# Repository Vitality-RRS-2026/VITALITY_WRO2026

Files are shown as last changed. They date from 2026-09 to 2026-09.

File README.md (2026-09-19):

<p align="center">
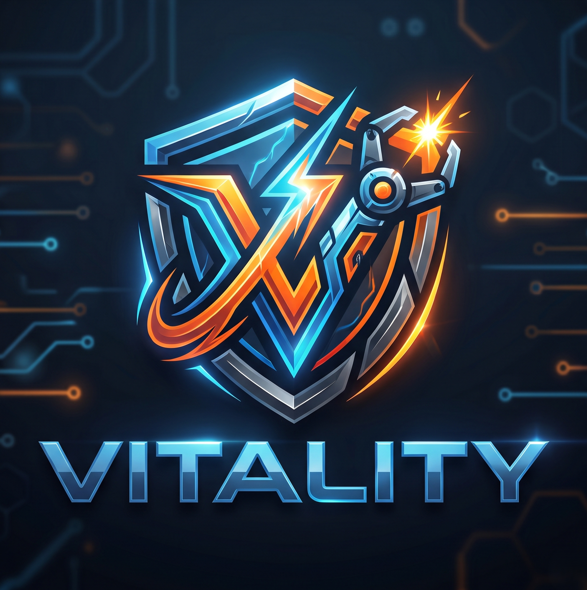
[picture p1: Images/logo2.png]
Team Vitality logo
  
</p>

<h1 align="center">⚡ WRO 2026 Future Engineers — Team Vitality</h1>

<p align="center">
  <a href="https://www.instagram.com/vitality2026.wro?stkn=dWI4NWJjdDJrMzQw">
    
  </a>
  <a href="https://youtu.be/qGNv-WUXziQ">
    
  </a>
</p>

---

## 👥 The Team

We are **Team Vitality**, three final-year high school students from Nairobi,
Kenya, competing in the **World Robot Olympiad™ (WRO®) Future Engineers 2026**
category.

| Member | Age | Year |
|---|---|---|
| **Ronak Agarwal** | 17 | Final year of high school |
| **Saurabh Rawat** | 17 | Final year of high school |
| **Raghav Mathur** | 17 | Final year of high school |

<!-- TEAM PHOTO — replace when uploaded -->
<p align="center">
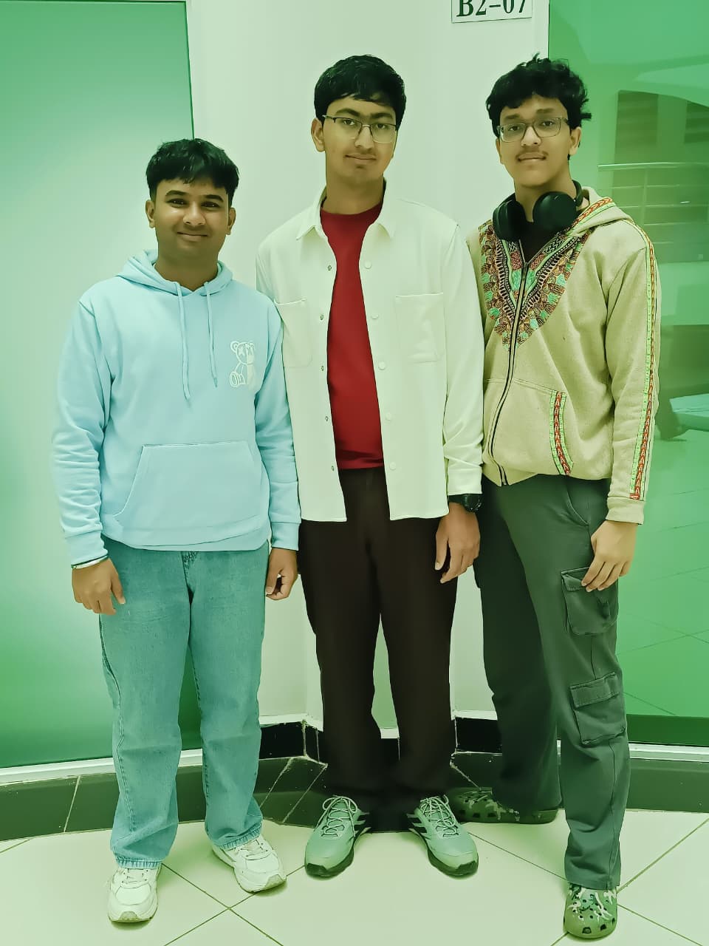
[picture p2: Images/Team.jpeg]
Team Photo
  
</p>

This is our first year in the Future Engineers category. We designed our own
Ackermann steering axle rather than buying an RC chassis, built the vehicle
around an **ESP32** and an **OpenMV Cam H7+**, and debugged our way through a
series of genuinely difficult electrical and mechanical failures — all of which
are documented honestly below, because that is where most of the engineering
actually happened.

*Last updated: [DATE]*

---

## 📸 The Vehicle

<table>
  <tr>
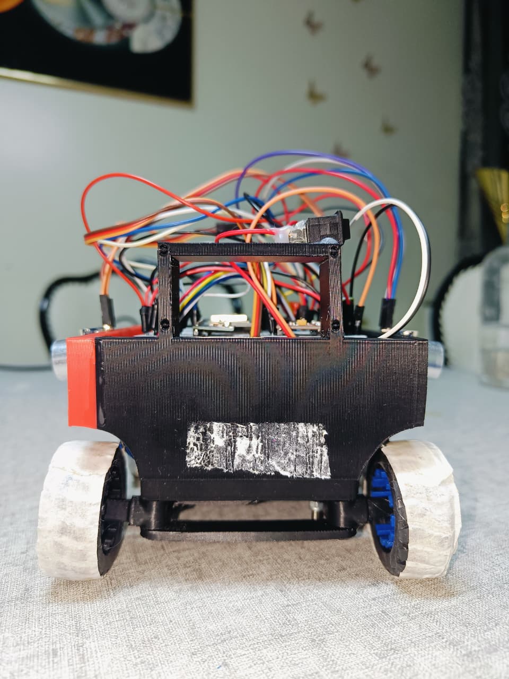
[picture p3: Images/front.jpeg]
    <td align="center"><br><b>Front</b></td>
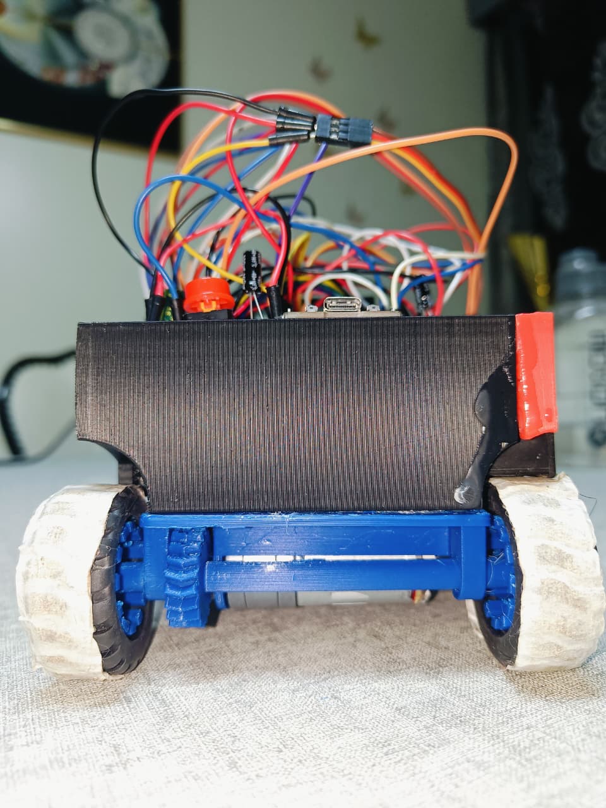
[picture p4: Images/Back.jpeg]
    <td align="center"><br><b>Back</b></td>
  </tr>
  <tr>
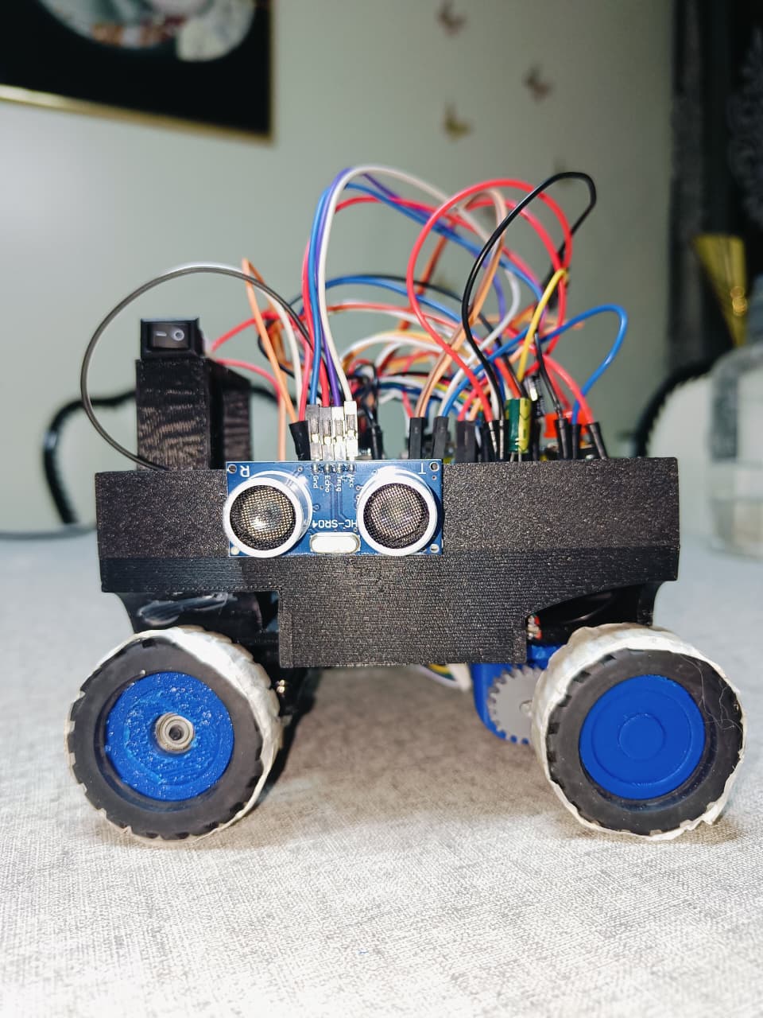
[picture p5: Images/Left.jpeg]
    <td align="center"><br><b>Left</b></td>
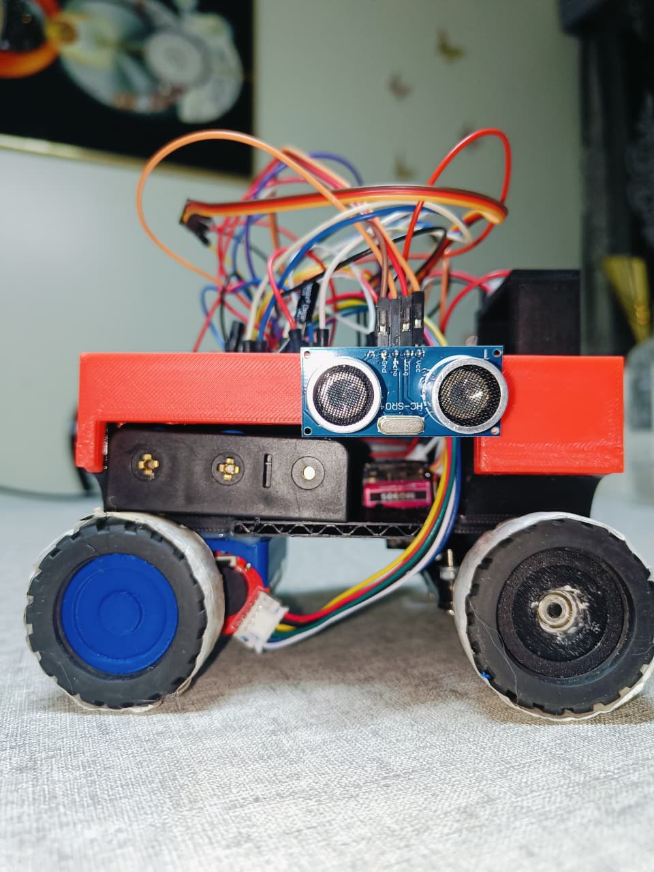
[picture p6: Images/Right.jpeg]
    <td align="center"><br><b>Right</b></td>
  </tr>
  <tr>
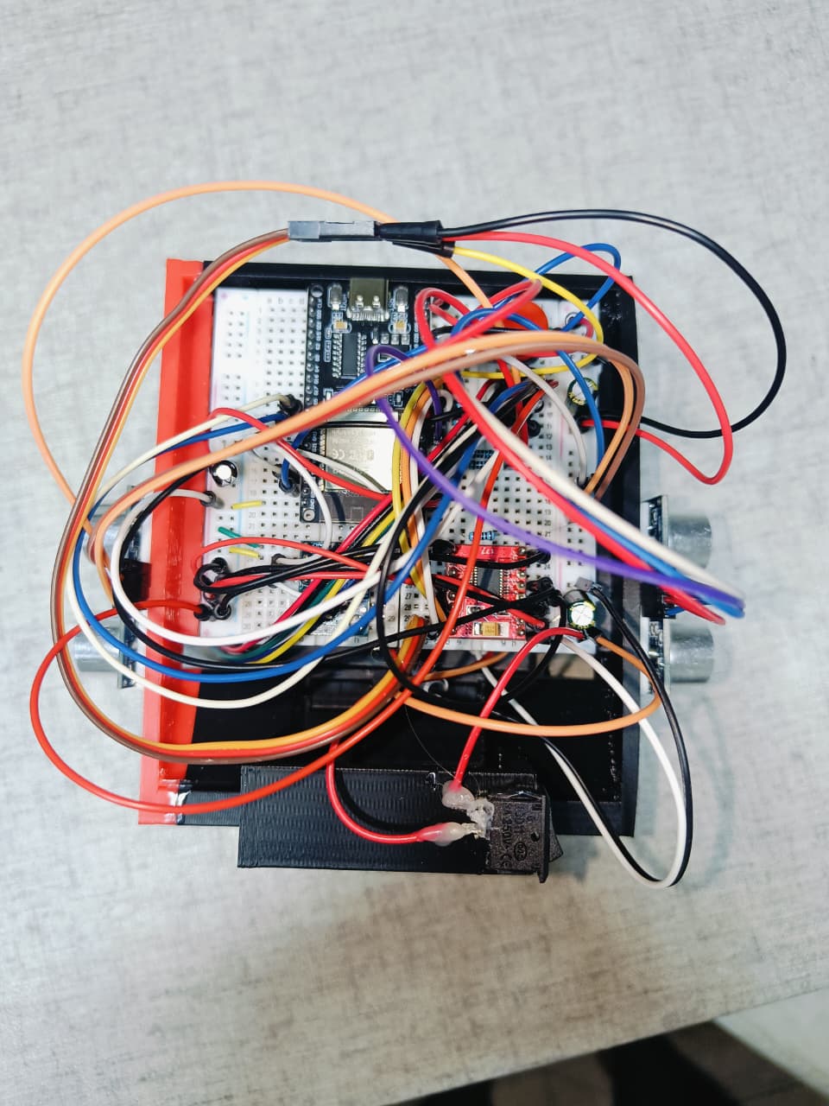
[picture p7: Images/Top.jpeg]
    <td align="center"><br><b>Top</b></td>
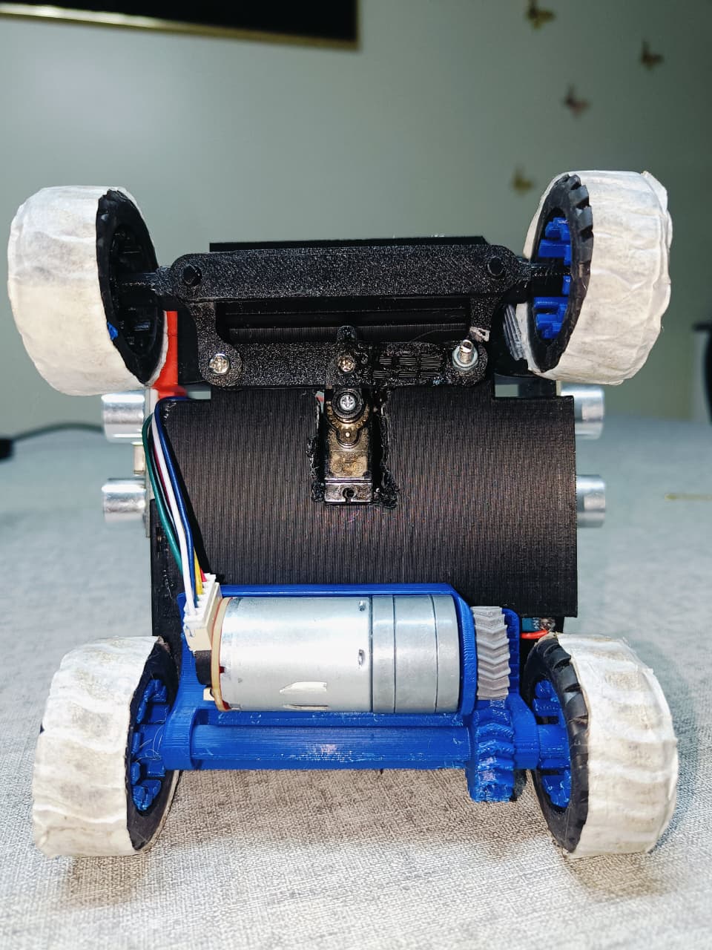
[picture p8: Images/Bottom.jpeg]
    <td align="center"><br><b>Bottom</b></td>
  </tr>
</table>

**Front** — the forward ultrasonic sensor mount and the Ackermann front axle.
**Back** — the rear drive axle, motor and gear train.
**Left / Right** — the two side ultrasonic sensors that drive wall following,
mounted level with the chassis so their readings stay square to the walls.
**Top** — ESP32 on a breadboard with the full wiring loom.
**Bottom** — the underside showing the steering linkage, servo, and the blue
rear axle assembly with the motor driving through a gear pair.

---

## 🔧 Where It Was Built

<p align="center">
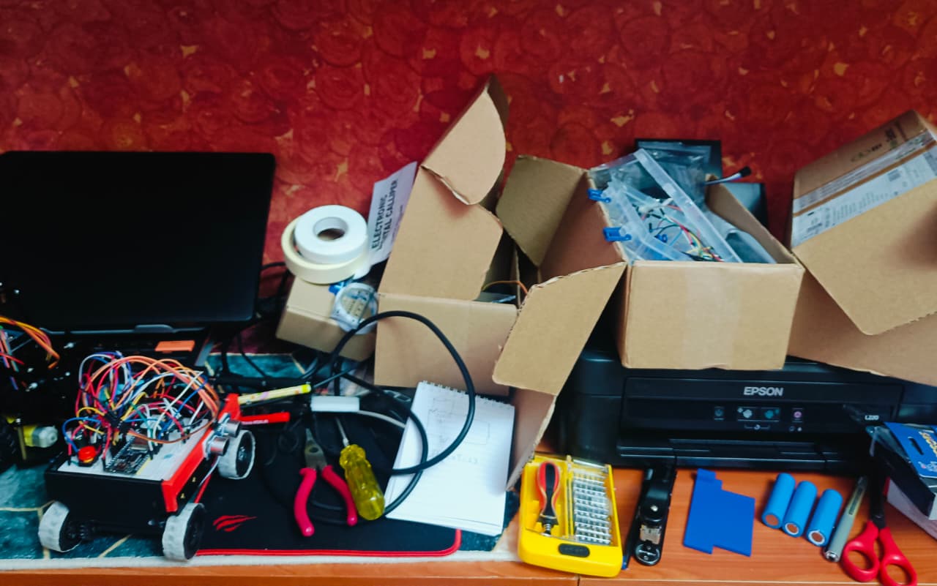
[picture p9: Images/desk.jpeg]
  <br>
  <em>The workbench through the build — prototyping, debugging and a great
  many spare parts.</em>
</p>

---

## 📑 Table of Contents

- [📸 The Vehicle](#-the-vehicle)
- [🎯 Challenge Overview](#-challenge-overview)
- [🤖 Our Vehicle](#-our-vehicle)
- [⚙️ Mobility and Mechanical Design](#️-mobility-and-mechanical-design)
- [🔋 Power and Sensor Architecture](#-power-and-sensor-architecture)
- [🧩 Components](#-components)
- [🖨️ 3D Printed Models](#️-3d-printed-models)
- [💻 Software Architecture](#-software-architecture)
- [⚖️ Engineering Decisions and Trade-offs](#️-engineering-decisions-and-trade-offs)
- [🔥 Failure Log](#-failure-log)
- [🛠️ Build and Upload Instructions](#️-build-and-upload-instructions)
- [🚧 Known Limitations and Future Work](#-known-limitations-and-future-work)
- [📜 License](#-license)

---

## 🎯 Challenge Overview

The competition runs on a 3000 × 3000 mm track with two challenges.

### 🏁 Open Challenge

Three autonomous laps. Inner wall positions are randomised per round, so each of
the four sections is either **1000 mm or 600 mm wide**, decided by coin toss
after the check time. The starting section, starting zone, and driving direction
(clockwise or counter-clockwise) are also randomised.

**What this forces on the design:** nothing about the track can be hard-coded.
The robot must discover its driving direction at runtime and tolerate a lane
that narrows by 40% without warning.

### 🚧 Obstacle Challenge

Three laps with red and green pillars (50 × 50 × 100 mm) placed randomly, then
parallel parking between two magenta markers.

Per the rules, a **red pillar means keep to the right side of the lane** and a
**green pillar means keep to the left**. Passing a pillar on the wrong side ends
the round as soon as the vehicle fully crosses the line where that pillar sits —
an incorrect pass is not a small penalty, it terminates the run.

---

## 🤖 Our Vehicle

| Property | Value | Limit |
|---|---|---|
| Dimensions (L × W × H) | **140 × 140 × 150 mm** | 300 × 200 × 300 mm ✅ |
| Mass | **550–600 g** | 1500 g ✅ |
| Drive | Rear-wheel drive, single GA25-370 geared motor with encoder | — |
| Steering | Front Ackermann axle, MG90S servo | — |
| Controller | ESP32 (ESP32-WROOM-32) | — |
| Vision | OpenMV Cam H7+ over UART | — |
| Battery | 3S Li-ion (11.1 V nominal, 12.6 V full) | — |

<p align="center">
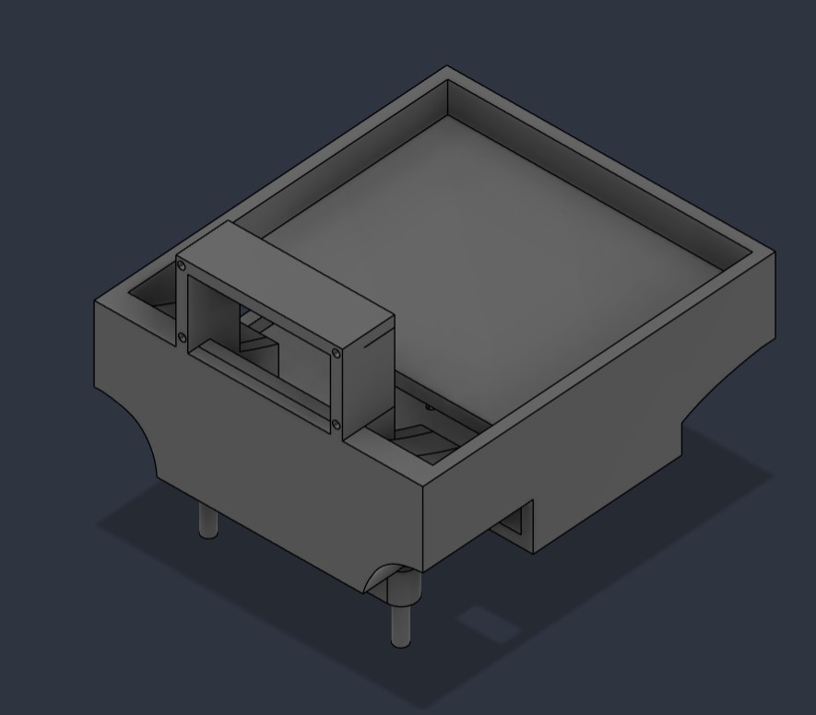
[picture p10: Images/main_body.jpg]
Main chassis CAD
  <br>
  <em>Main chassis — electronics bay, camera mast, and integrated front axle mount</em>
</p>

---

## ⚙️ Mobility and Mechanical Design

### 🔩 Why Ackermann steering

The rules require a vehicle with **one driving axle and one steering actuator**,
and explicitly disqualify differential-drive robots. We designed our own front
Ackermann axle so that we could control — and justify — every dimension.

Ackermann geometry angles the two front wheels differently in a turn so both
roll along arcs about a common centre instead of scrubbing. The steering arm on
each knuckle must point from its **kingpin** at the centre of the rear axle.

<p align="center">
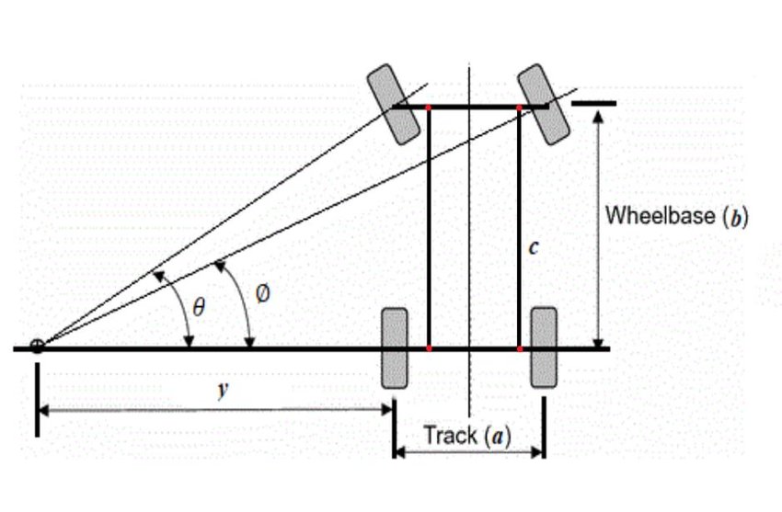
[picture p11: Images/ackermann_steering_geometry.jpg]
Ackermann geometry
  <br>
  <em>Ackermann geometry: inner wheel angle θ and outer wheel angle Ø differ so both
  wheels share one turn centre. Track (a), wheelbase (b).</em>
</p>

```
arm angle = atan(kingpin_offset / wheelbase)
```

**This is where we made our first significant error.** Our initial design used
half the track width instead of the kingpin offset, giving 24.2°. The correct
figure for our geometry is:

```
atan(27 mm / 100 mm) = 15.1°
```

The wrong value produces excessive toe-out in corners — the inner wheel steers
far more than the geometry wants and both tyres scrub. We caught it while
re-deriving the linkage from first principles and corrected it.

### 📐 Turning radius

```
R = wheelbase / tan(wheel angle)
```

| Wheel angle | Radius (mm) | 90° arc length (mm) |
|---|---|---|
| 10° | 567 | 891 |
| 15° | 373 | 586 |
| 20° | 275 | 432 |
| 25° | 214 | 337 |

Our linkage (10 mm horn arm driving a 20 mm knuckle arm, ratio 0.5) initially
gave only about 11° at the wheels from ±25° of servo travel — a **500 mm
radius**, too wide for the corners. We increased steering travel after measuring
this.

Rather than trusting the formula, the robot **measures its own turning radius**
using `R = arc_length / angle_in_radians`, taking arc length from the encoder and
angle from the gyro. This captures tyre slip and linkage slop that the formula
ignores.

### 🔧 The steering mechanism

<p align="center">
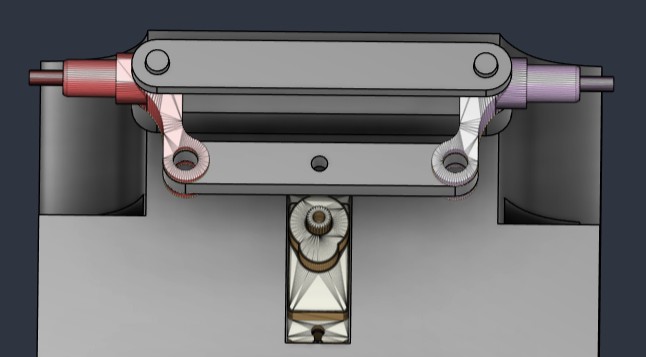
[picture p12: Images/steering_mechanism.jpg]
Steering mechanism assembly
  <br>
  <em>Complete front axle: servo (bottom centre) drives the horn, which pushes two
  tie rods out to the left and right steering arms. Both knuckles pivot on kingpins.</em>
</p>

<p align="center">
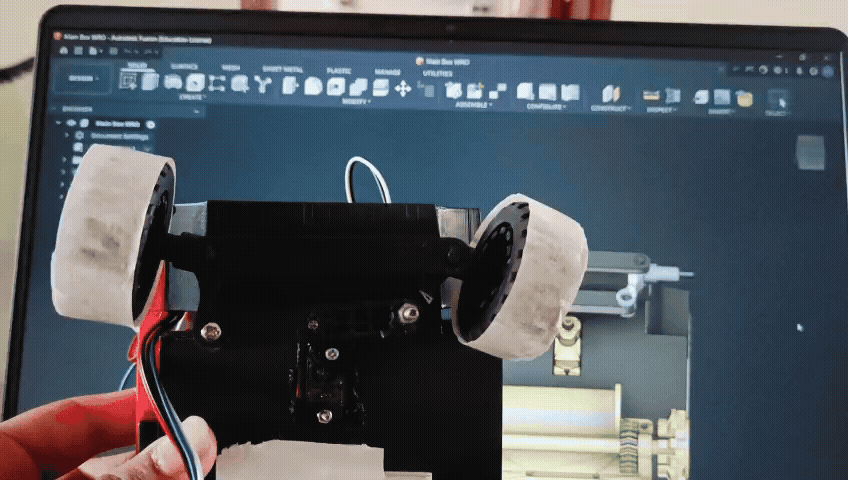
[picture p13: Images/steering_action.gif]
Steering in motion
  <br>
  <em>The assembled mechanism steering through its full travel</em>
</p>

### 🏗️ Structural iteration

The first knuckle design hung from a single M3 bolt threaded into the base plate
— a cantilever in single shear, with the wheel load acting 18 mm outboard of the
kingpin. We identified this as a failure point **before** it broke and redesigned
it as a **yoke**: the kingpin now passes through the plate, the knuckle, and a
lower arm beneath, capturing it at both ends in **double shear**.

The support towers are **lofted rather than straight** — narrow at the pivot,
flaring where they meet the plate. This gives a root cross-section of about
225 mm² against 72 mm² for a plain column: a **3.1× increase** exactly where the
bending moment is highest. A cross-beam ties the two towers together, making
plate, towers and beam a single rigid axle carrier.

### 🛞 The scrub problem (unresolved)

<p align="center">
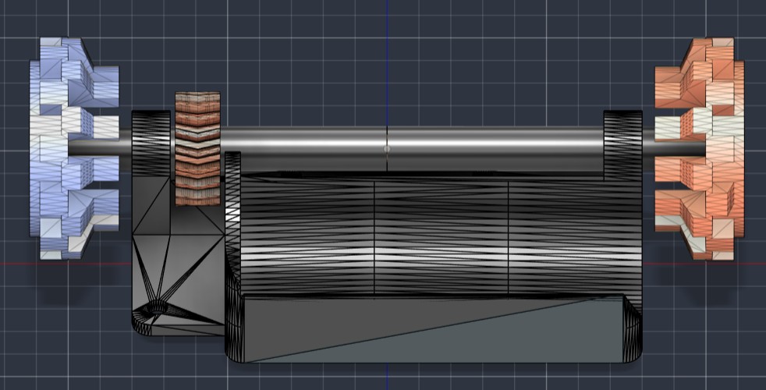
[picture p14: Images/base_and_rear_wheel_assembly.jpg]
Rear axle assembly
  <br>
  <em>Rear axle: both wheels fixed to a single solid shaft driven by the motor</em>
</p>

Our rear axle is a solid shaft — both wheels turn at the same speed. In a corner
the outer wheel must travel further than the inner one, and the difference is
fixed by track width alone:

```
difference = track_width × turn_angle_in_radians
           = 90 mm × (π/2) = 141 mm per 90° corner
```

Over 12 corners that is **1.7 metres of forced tyre scrub**. It does not improve
with a wider turn — only track width matters.

**Options we evaluated:**

| Option | Effect | Cost | Decision |
|---|---|---|---|
| Bevel-gear differential | Eliminates scrub | Days of CAD; printed bevel gears usually bind at this scale | ❌ Not achievable in remaining time |
| Free one rear wheel | Eliminates scrub | 15 minutes | ❌ Rejected on rules risk — drive wheels must be physically connected |
| Low-friction tape on rear tyres | Reduces grip so wheels slip | 5 minutes | ❌ Tried, no measurable improvement — tape over knobbly tread doesn't sit flat |
| Narrow the rear tyres | Smaller contact patch resists twisting less | 20 minutes | ⏳ Recommended next step |
| Reduce cornering speed | Spreads scrub over time rather than reducing it | Free | ✅ Implemented as mitigation |

This is an honest open problem in our design and the clearest target for our next
iteration.

---

## 🔋 Power and Sensor Architecture

### ⚡ The power failure that cost us the most time

Our original design used a **2S Li-ion pack (8.4 V)** with:
- a **CN6009 boost converter** raising 8.4 V → 12 V for the motor
- an **LM2596 buck converter** dropping 8.4 V → 5 V for everything else

The robot worked on a fully charged pack and failed completely once cell voltage
fell from 4.20 V to 4.15 V. A 0.05 V change causing total failure is not how a
battery problem behaves — that sharp threshold pointed at a regulator.

**Root cause: a boost converter draws more current in than it delivers out.**

```
input current = (output voltage × output current) / (input voltage × efficiency)
```

| Pack voltage | Motor at 1.0 A | Motor at 2.0 A |
|---|---|---|
| 8.4 V | 1.68 A | 3.36 A |
| 8.0 V | 1.76 A | 3.53 A |
| 7.2 V | 1.96 A | 3.92 A |

As the pack sags, the boost converter demands **more** input current for the same
output. More current through holder and wiring resistance causes more sag. It is
a positive feedback loop, which is why it failed at a cliff edge instead of
degrading gradually.

**Solution: switch to 3S and delete the boost converter.** The motor now runs
directly from the pack.

| | 2S + boost | 3S direct |
|---|---|---|
| Battery current for 1 A motor | 1.68 A | 1.00 A |
| Converters in the motor path | 1 | 0 |
| Failure points | 3 | 2 |

This cut battery current by **43%** for the same motor power and removed the
feedback loop entirely.

### 🔍 Chasing 1.4 volts

Even on 3S the ESP32 reset whenever the servo moved. We measured the whole path
rather than guessing:

| Measurement point | Voltage |
|---|---|
| LM2596 output, no load | 5.11 V |
| 5 V rail, loaded | 4.90 V |
| **ESP32 VIN pin** | **3.80 V** |

The ESP32's onboard AMS1117 regulator needs roughly 1.2 V of headroom above
3.3 V. At 3.8 V it had 0.5 V and browned out. The loss was **resistance in the
wiring**, not a converter fault.

**Fixes applied:**
1. Replaced jumper wires and DuPont connectors on all power paths with **20 AWG
   silicone wire, soldered**. DuPont crimps are rated well below the 1–3 A a
   motor draws and loosen under vibration.
2. Raised converter output to compensate for the remaining drop.
3. Added **electrolytic capacitors at the loads, not at the converter** — wire
   between reservoir and load blunts the effect.

Result: rail sag under servo load fell from **0.44 V to 0.11 V**.

### 🎚️ Servo selection — measured, not guessed

We calculated the steering torque actually required rather than buying the
biggest servo available. Stationary steering torque is dominated by **scrub
torque**, because the kingpin is offset from the wheel centreplane:

```
scrub radius   = 45 mm − 27 mm = 18 mm
load per wheel = 1.5 kg × 0.45 × 9.81 / 2 = 3.31 N
scrub torque   = μ × N × r = 1.1 × 3.31 × 0.018 = 6.56 N·cm per wheel
```

Adding bore torque and both wheels gives **1.51 kg·cm at the kingpins**. The
linkage ratio (0.5) means the servo sees half: **0.76 kg·cm**.

| Servo | Torque at 6 V | Mass | Margin |
|---|---|---|---|
| **MG90S** | 2.2 kg·cm | 13.4 g | **2.9×** |
| MG996R | 11.0 kg·cm | 55.0 g | 14.6× |

**We chose the MG90S.** The MG996R offers a 14.6× margin we have no use for,
while costing 42 g and occupying 37% of the chassis width. It is also an analog
servo with significant gear backlash, and our 0.5 linkage ratio *amplifies*
backlash into wheel wander — precision matters more than torque here.

### 📡 Sensor placement

| Sensor | Purpose | Placement rationale |
|---|---|---|
| 2 × HC-SR04 ultrasonic | Wall following, corner detection | Left and right, facing outward. Lane is 600–1000 mm wide, well within range |
| MPU6050 IMU | Heading during turns | Gyro Z axis only; accelerometer unused |
| Motor encoder | Distance, turning-radius measurement | On the drive motor |
| OpenMV Cam H7+ | Pillar colour and position | Forward-facing on a mast, tilted down |

The ultrasonics fire **one per control loop, alternating**. Firing both together
causes crosstalk — each hears the other's echo. Their ECHO pins connect through
**1 kΩ / 2 kΩ dividers** to drop the 5 V signal to 3.33 V, and use GPIO 34 and
35, which are input-only.

### 🔌 Pin map

| GPIO | Function |
|---|---|
| 14 | Servo signal |
| 16 / 17 | UART2 RX / TX ↔ OpenMV camera |
| 18 / 19 | Encoder A / B |
| 21 / 22 | I²C SDA / SCL (MPU6050) |
| 23 | Start button → GND |
| 25 / 26 / 27 | Motor PWMA / AIN1 / AIN2 |
| 32 / 33 | Ultrasonic TRIG left / right |
| 34 / 35 | Ultrasonic ECHO left / right (input-only) |

---

## 🧩 Components

| Component | Image | Qty | Function | Key specifications |
|---|---|---|---|---|
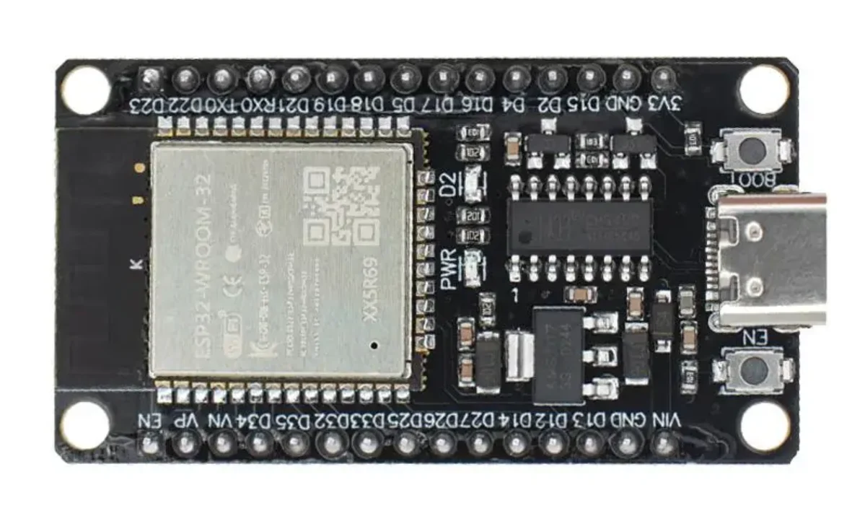
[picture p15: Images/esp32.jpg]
| **ESP32-WROOM-32** |  | 1 | Main controller | Dual-core 240 MHz, 3.3 V logic, runs all control and sensing |
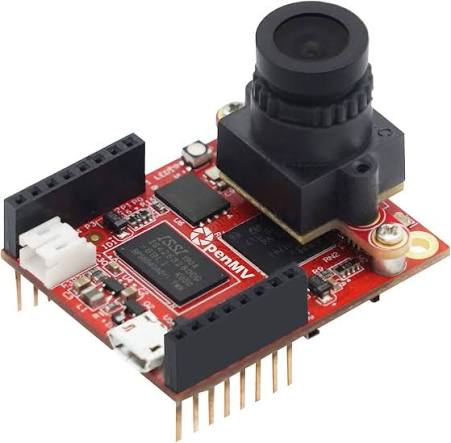
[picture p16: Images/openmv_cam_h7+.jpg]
| **OpenMV Cam H7+** |  | 1 | Vision processing | STM32H7, QVGA capture, on-board LAB blob detection |
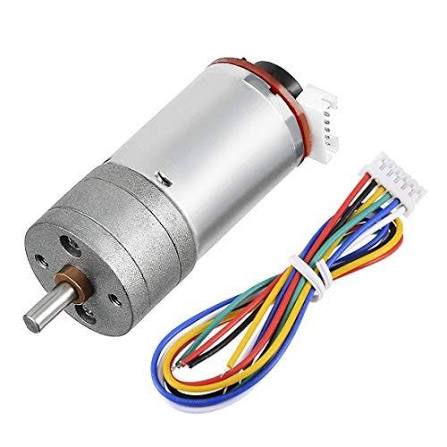
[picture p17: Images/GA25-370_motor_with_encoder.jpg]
| **GA25-370 geared motor** |  | 1 | Rear-wheel drive | 12 V DC, integrated quadrature encoder (6 wires) |
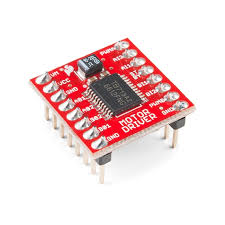
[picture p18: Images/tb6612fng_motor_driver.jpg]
| **TB6612FNG driver** |  | 1 | Motor control | Dual H-bridge, VM to 13.5 V, 3.3 V logic |
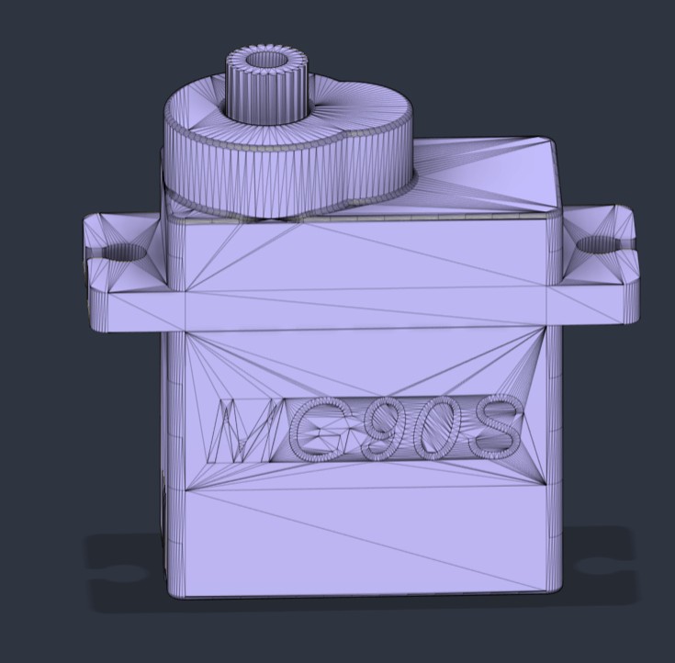
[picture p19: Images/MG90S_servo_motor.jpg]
| **MG90S servo** |  | 1 | Steering actuation | 2.2 kg·cm at 6 V, metal gears, 13.4 g |
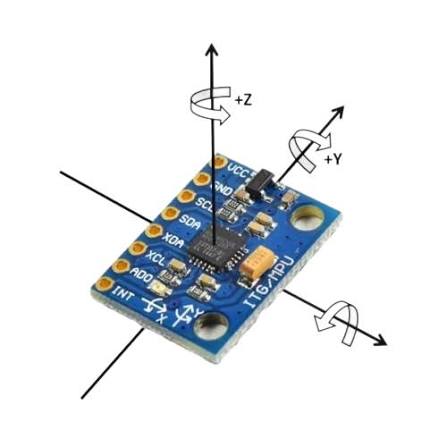
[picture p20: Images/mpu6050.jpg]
| **MPU6050 IMU** |  | 1 | Heading measurement | 6-axis, I²C, gyro Z used for yaw integration |
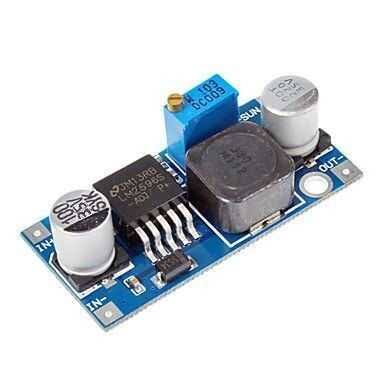
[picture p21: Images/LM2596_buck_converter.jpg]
| **LM2596 buck converter** |  | 1 | 12.6 V → 5 V | 4–35 V in, adjustable out, ~92% efficiency |
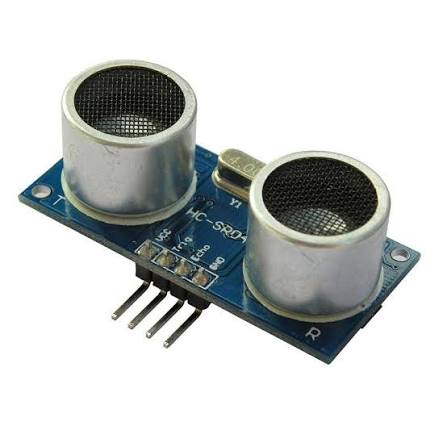
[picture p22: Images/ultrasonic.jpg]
| **HC-SR04 ultrasonic** |  | 2 | Wall distance | 5 V, 2–400 cm, ECHO through 1k/2k divider |
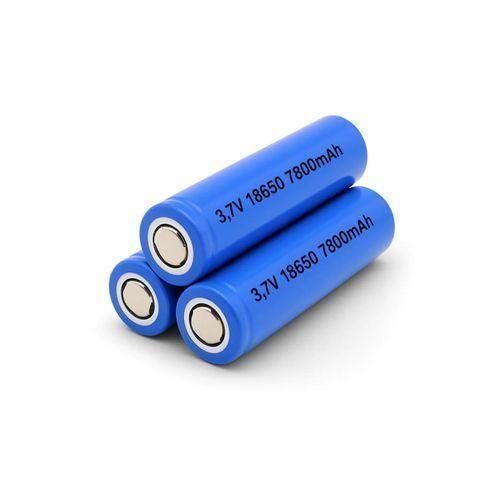
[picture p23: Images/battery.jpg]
| **3S Li-ion pack** |  | 1 | Power source | 11.1 V nominal, 12.6 V full |
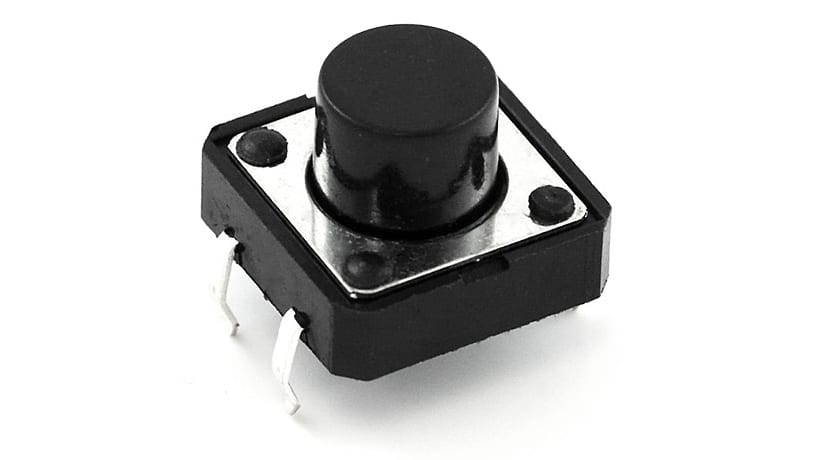
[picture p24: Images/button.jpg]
| **Push button** |  | 1 | Start trigger | GPIO 23 to GND, `INPUT_PULLUP` |

**Component selection philosophy:** we deliberately chose widely available,
well-documented parts so another team can source and reproduce this build. Every
component above is stocked by general electronics suppliers.

---

## 🖨️ 3D Printed Models

All structural parts were designed in **Fusion 360** and printed in PLA.

| Part | Image | Qty | Function |
|---|---|---|---|
| **Main body** |  | 1 | Primary chassis — electronics bay, camera mast mount, front axle interface |
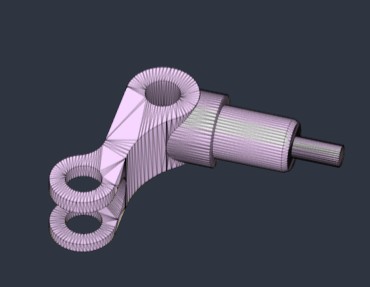
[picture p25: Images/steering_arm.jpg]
| **Steering arm (knuckle)** |  | 2 | Carries the stub axle and pivots on the kingpin; the angled arm sets Ackermann geometry |
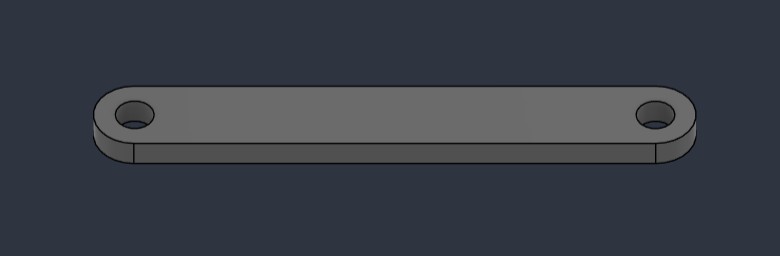
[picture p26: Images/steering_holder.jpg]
| **Steering holder** |  | 1 | Servo mount and kingpin support structure |
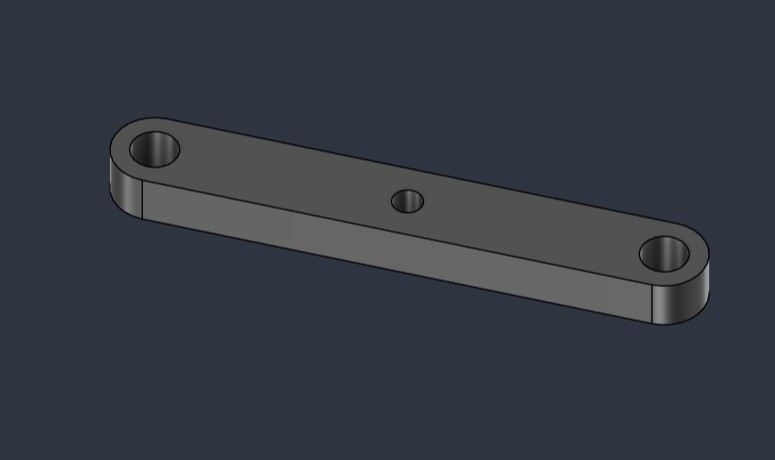
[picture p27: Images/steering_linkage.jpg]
| **Steering linkage (tie rod)** |  | 2 | Connects the servo horn to each steering arm |
| **Servo horn / bell crank** |  | 1 | Converts servo rotation into linear tie-rod motion |
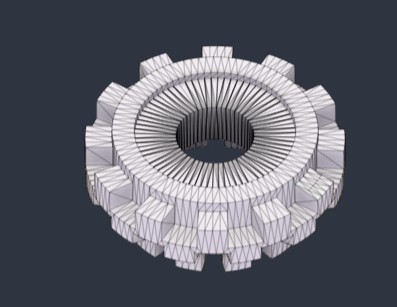
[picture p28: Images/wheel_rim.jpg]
| **Wheel rim** |  | 4 | Printed rim; rubber tyre fitted over the tread pattern |
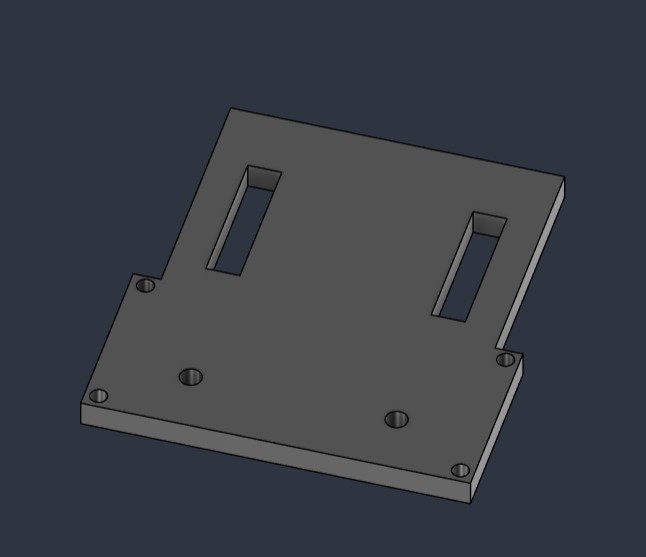
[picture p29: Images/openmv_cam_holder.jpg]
| **OpenMV camera holder** |  | 1 | Mounts the camera at a fixed downward tilt so the view stays repeatable |

<p align="center">
  Steering arm detail
  Steering linkage detail<br>
  <em>Left: steering arm with integrated stub axle and angled Ackermann arm.
  Right: tie rod linking horn to knuckle.</em>
</p>

**Print notes:** parts print without supports in the orientations supplied.
The steering components use higher perimeter counts, since the tie rods and
steering arms carry the full cornering load through relatively thin sections.

---

## 💻 Software Architecture

### 🔀 Processing split

```
OpenMV Cam H7+                    ESP32
──────────────                    ─────
Image capture                     Ultrasonic ranging
LAB colour thresholding    UART   Gyro integration
Blob detection            ─────▶  State machine
Dominant colour choice    115200  PD wall following
                                  Servo + motor output
```

Vision runs entirely on the OpenMV so the ESP32 never blocks on image processing.
The link is one-way at 20 Hz; the ESP32 control loop runs at 50 Hz.

### 🔄 Open Challenge state machine

```
   ┌──────┐  button   ┌───────┐  wall lost   ┌─────────┐
   │ WAIT │ ────────▶ │ DRIVE │ ───────────▶ │ TURNING │
   └──────┘           └───────┘              └─────────┘
                          ▲                       │
                          └───────────────────────┘
                            90° swept, heading snapped

   after 12 corners:  DRIVE ──▶ FINISHING ──▶ DONE
```

### 🧭 Wall following

<p align="center">
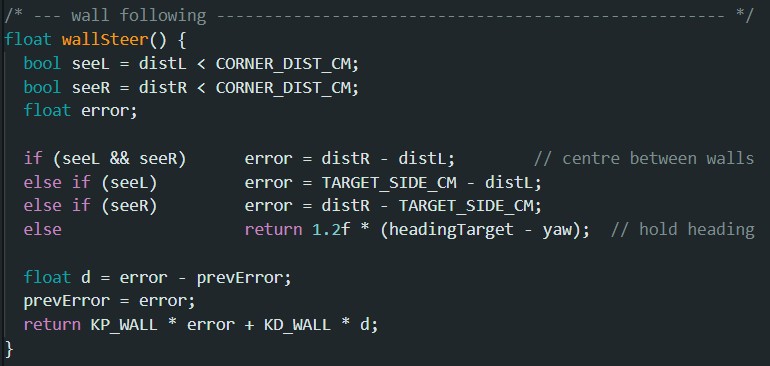
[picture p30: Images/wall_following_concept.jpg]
Wall following code
  <br>
  <em>PD wall-following controller with graceful degradation as walls disappear</em>
</p>

The controller handles four cases in priority order:

1. **Both walls visible** — centre between them: `error = distR − distL`
2. **Only left wall** — hold a fixed offset from it
3. **Only right wall** — hold a fixed offset from it
4. **Neither wall** — fall back to holding the gyro heading

This graceful degradation matters because the lane width changes between
sections, and at a corner one wall genuinely disappears.

### 🔁 Corner turns and drift control

<p align="center">
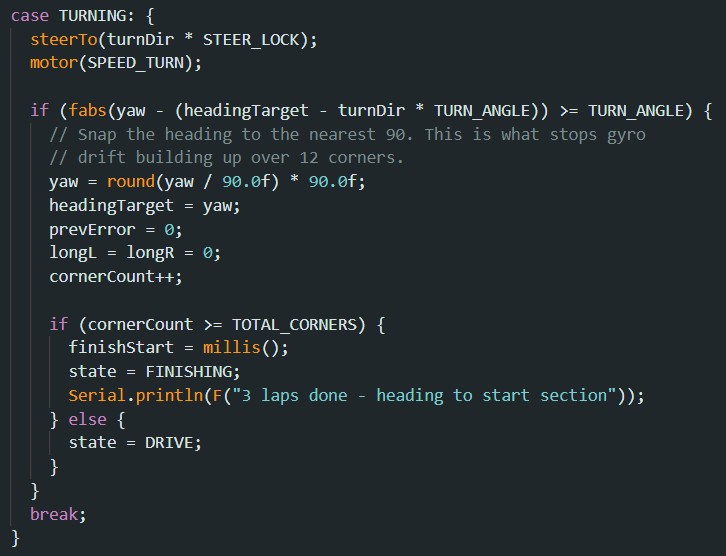
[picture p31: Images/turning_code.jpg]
Turning state machine code
  <br>
  <em>The TURNING state: gyro-measured 90° turn followed by heading snapping</em>
</p>

**Turns use the gyro, not a timer.** A timed turn varies with battery voltage and
floor grip, so it drifts over 12 corners. "Turn until the gyro says 90°" is
repeatable.

The MPU6050 reports angular *rate*, so heading comes from integration:

```
yaw += (rate − bias) × dt
```

Three measures keep drift bounded:

1. **Bias calibration** — 1500 samples averaged at startup with the robot still
2. **Deadband** — rates below 0.6 °/s treated as zero, so noise on straights
   doesn't accumulate
3. **Heading snapping** — after each corner, yaw resets to the nearest multiple
   of 90°, so each corner corrects the previous straight's error instead of
   compounding it

The third is the single most effective measure, and it is visible in the code
screenshot above.

### 🧠 Direction detection

Driving direction is randomised per round. The robot **decides at the first
corner** — whichever wall disappears first sets the turn direction, which is then
fixed for the entire run. Driving the wrong way ends the round, so this value is
never revised mid-run.

### 🎨 Vision pipeline

<p align="center">
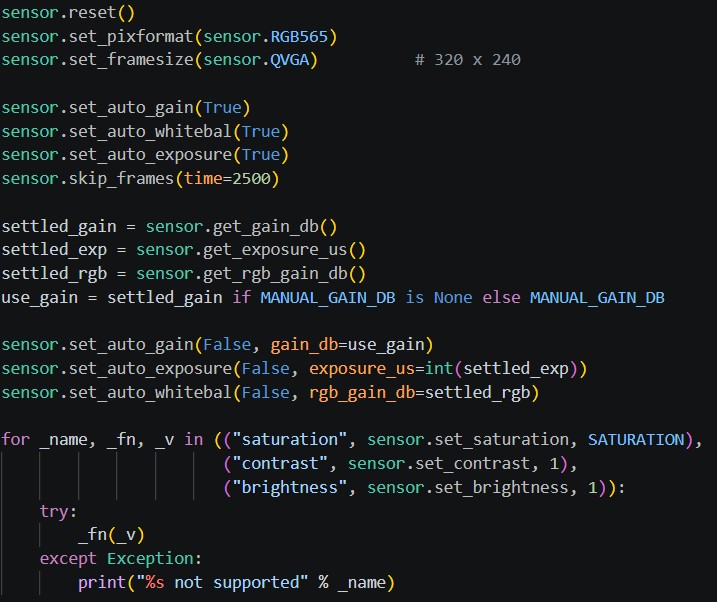
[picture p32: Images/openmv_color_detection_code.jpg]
Camera initialisation code
  <br>
  <em>Camera setup: auto-exposure settles, then gain, exposure and white balance
  are read back and locked so thresholds stay valid</em>
</p>

The locking step matters more than it looks. If auto-gain and auto-white-balance
stay enabled, the sensor continuously re-balances and the LAB thresholds drift
out from under the detection code. We let auto settle, read the settled values,
then fix all three.

**Pipeline:**
1. Capture 320 × 240 RGB565
2. Lock gain, exposure, white balance; raise saturation
3. Convert to LAB and threshold
4. Blob detection with merging, restricted to a region of interest cropping off
   the far wall
5. Choose dominant colour by **total pixel area**, take position from the
   **largest single blob** of that colour

That last distinction is deliberate. Total area answers "which colour dominates";
using it for position too would average two pillars into the gap between them,
and the robot would steer at the gap.

### 🌈 Why LAB and not RGB

LAB separates lightness (L) from colour (A and B), so a dimmer pillar of the same
colour still matches. Thresholds were derived from the official pillar colours
rather than eyeballed:

| Object | RGB | L | A | B |
|---|---|---|---|---|
| Red pillar | (238, 39, 55) | 51.7 | 72.1 | 42.7 |
| Green pillar | (68, 214, 44) | 75.8 | −67.3 | 66.4 |
| Magenta marker | (255, 0, 255) | 60.3 | 98.2 | −60.8 |

**Red and magenta are both strongly positive on A.** They separate only on B,
where red is +42.7 and magenta is −60.8. Knowing this made tuning
straightforward: if magenta reads as red, raise red's B minimum.

We also checked the **orange and blue direction lines** against the pillars. The
orange line sits only 41 units from red in LAB — close enough that lighting
variation will confuse them. Blue is 109 from red and 117 from orange. If we use
the lines for lap counting, we will **count blue only**.

### ▶️ Start procedure

The rules require one switch to power the robot on and a **separate button** to
start the program, and flag auto-start as a recurring source of penalties. Our
robot powers on, calibrates the gyro, prints `READY`, and waits on a debounced
button (GPIO 23, `INPUT_PULLUP`). Yaw zeroes on the press rather than at
power-up, so the heading reference is where the robot actually sits at the start.

---

## ⚖️ Engineering Decisions and Trade-offs

| Decision | Alternative | Why we chose it | What it costs |
|---|---|---|---|
| 3S direct drive | 2S + boost converter | Removes current-multiplication feedback loop; 43% less battery current | Extra cell mass; must not over-discharge |
| MG90S servo | MG996R | 2.9× margin is enough; saves 42 g and 37% of chassis width | Less headroom if the robot gains weight |
| Gyro-timed turns | Fixed-duration turns | Repeatable regardless of battery state | Requires IMU and calibration |
| Heading snap at corners | Continuous integration | Bounds drift instead of letting it compound | Assumes every corner is exactly 90° |
| Vision on OpenMV | Vision on ESP32 | ESP32 never blocks on image processing | Extra board and a UART link to debug |
| LAB colour space | RGB or HSV | Tolerates brightness variation | Thresholds less intuitive to read |
| Dominant colour by area, position by largest blob | Either alone | Avoids steering at the gap between two pillars | Slightly more computation |
| Ultrasonics alternating | Both simultaneously | Eliminates crosstalk | Halves update rate per sensor |
| Printed Ackermann axle | Bought RC chassis | Full control of geometry; every dimension justified | Several print-and-test cycles |
| Open Challenge first | Both challenges at once | Secures the achievable points before attempting the harder round | Obstacle Challenge left incomplete |

---

## 🔥 Failure Log

Documented honestly, because the debugging is where most of the engineering
happened.

| Symptom | Actual cause | How we found it |
|---|---|---|
| Fusion script: *"No target body found to cut"* | Sketch plane exactly coincident with the face being cut | Traced to one operation, then made all cuts start 2 mm outside the material |
| Parts generated but disconnected | Support towers at Y=+11 while the plate ended at Y=+10 — a 1 mm gap. Fusion's Join silently does nothing when bodies don't touch | Checked coordinates numerically instead of visually |
| Knuckles buried 13 mm inside the wheels | Kingpin at ±38 mm with wheel inner face at ±35 mm | Compared geometry numerically — renders looked fine because separate components can interpenetrate |
| Battery collapsed 8.2 V → 0.8 V, wire overheated | Damaged cells and holder contact resistance | Measured under load rather than at rest |
| Worked at 4.20 V per cell, dead at 4.15 V | Boost converter current-multiplication feedback loop | The sharpness of the threshold pointed at a regulator, not a battery |
| ESP32 resetting whenever the servo moved | 1.4 V lost between rail and VIN pin in wiring and connectors | Measured voltage at four points along the path |
| OpenMV: *"'tuple' object isn't callable"* | Firmware 4.5+ changed blob accessors from methods to properties | Wrote a helper accepting both conventions |
| Camera image dark and desaturated | Scene under-lit; auto-exposure already at its limit | Measured frame brightness while sweeping gain and exposure |
| Servo wouldn't move in the combined sketch | ESP32Servo and motor PWM competing for LEDC timers | Worked in isolation; fixed by initialising the servo first on separate timers |
| Spark and bang; ESP32 destroyed | 12.6 V line contacted the 5 V rail | Visible component failure on the board |

**Mitigation after the short circuit:** inline fuse on the battery positive lead,
12.6 V and 5 V runs physically separated and routed on opposite sides, heatshrink
over every exposed terminal, and battery leads mechanically secured so they
cannot shift under vibration.

---

## 🛠️ Build and Upload Instructions

### Requirements

- **Arduino IDE** with ESP32 board support
- Library: **ESP32Servo** (Library Manager). The MPU6050 is driven through raw
  register access over `Wire.h`, so no IMU library is needed.
- **OpenMV IDE** for the camera

### ESP32

1. Open the sketch from `src/`
2. Select your ESP32 board and port
3. Set `TUNING_MODE` to `1` for the first upload — the motor stays disabled while
   sensors print at 10 Hz
4. Upload and open Serial Monitor at **115200**

### OpenMV

1. Open the `.py` file from `src/` in OpenMV IDE
2. Verify detection in the frame buffer
3. **Tools → Save open script to OpenMV Cam (As Main Script)** — pressing Run only
   loads it into RAM and it is lost on power-cycle

### 📋 Calibration order

These are interdependent; doing them out of order wastes time.

1. **`ENCODER_TICKS_PER_REV`** — rotate the wheel 10 turns by hand and read the
   count. Every distance measurement depends on it.
2. **Motor direction and deadband** — confirm forward gives positive ticks; find
   the lowest PWM that moves the shaft.
3. **`SERVO_CENTER`** — on blocks, adjust until the wheels are truly straight. An
   off-centre value makes the robot curve constantly and **no amount of PD tuning
   fixes it**. This is the most common cause of wall-following failure.
4. **`KP_WALL`** — raise until the robot weaves, then back off ~30%. Leave
   `KD_WALL` until KP is close.
5. **`CORNER_DIST_CM`** — read what the side sensors actually report on a
   straight, then set the threshold well above it.
6. **Colour thresholds** — OpenMV IDE → Tools → Machine Vision → Threshold Editor,
   under the lighting you will actually compete in.

---

## 🚧 Known Limitations and Future Work

We would rather state these plainly than omit them.

**Rear axle scrub.** No differential — 141 mm of forced scrub per corner. Next
step is narrowing the rear tyres; the proper fix is a differential.

**Obstacle Challenge incomplete.** Colour detection and steering response work,
but pillar avoidance is not reliable enough to compete, and parking is not
implemented. We prioritised a working Open Challenge over an unreliable Obstacle
attempt, because passing a pillar on the wrong side ends the round.

**Lighting dependence.** Until robot-mounted lighting is fitted, thresholds must
be re-tuned at the venue.

**No speed control loop.** The encoder measures distance but does not close a loop
on speed, so the robot slows as the battery drains. The PWM-to-speed curve is
markedly non-linear, which is why open-loop PWM is not equivalent to commanding a
speed.

**Timed finish.** Stopping in the start section uses a tuned drive time after the
twelfth corner rather than encoder distance — adequate, but sensitive to speed
changes.

### Planned improvements

- ⚙️ Differential, or narrowed rear tyres, to eliminate scrub
- 💡 Robot-mounted LEDs for lighting independence
- 🔁 Closed-loop speed control using the existing encoder
- 🔵 Blue-line counting as an independent cross-check on gyro corner counting
- 📏 Encoder-based finish positioning

---

## 📜 License

GNU Affero General Public License v3.0

This repository will remain public for at least 12 months after the competition.

---

<p align="center">
  Team Vitality<br>
  <strong>Team Vitality</strong><br>
  <em>WRO 2026 Future Engineers</em>
</p>

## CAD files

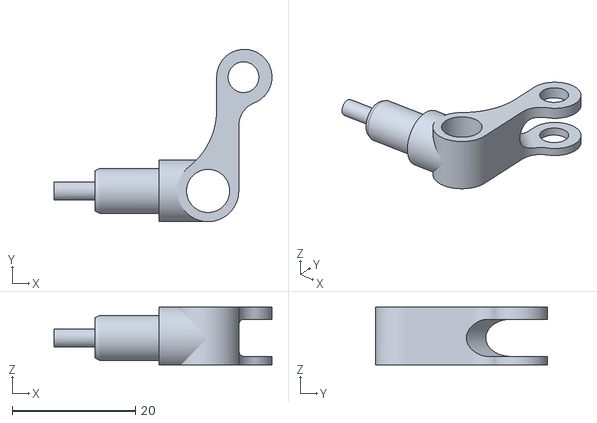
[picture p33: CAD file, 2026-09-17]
Finished Models/Main Box WRO_Configuration 1_design_steering_arm_left.stl
35.4 x 28.0 x 9.40

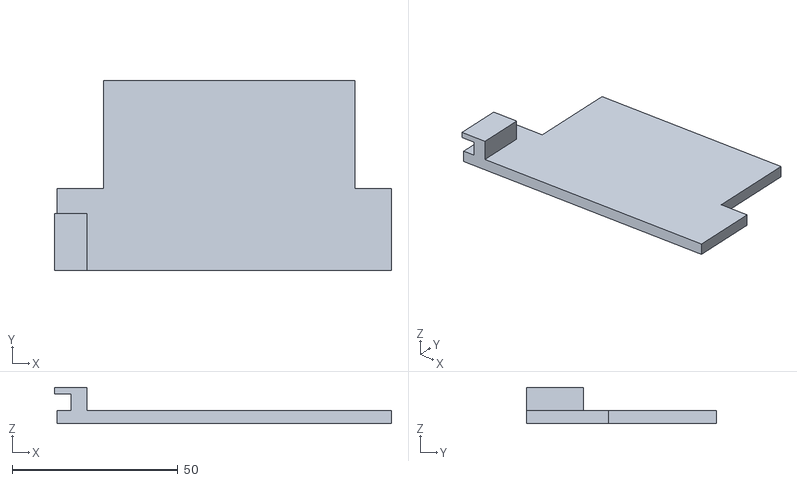
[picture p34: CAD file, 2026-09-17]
Finished Models/Main Box WRO_Configuration 1_Battery Holder.stl
101.7 x 57.3 x 11.0

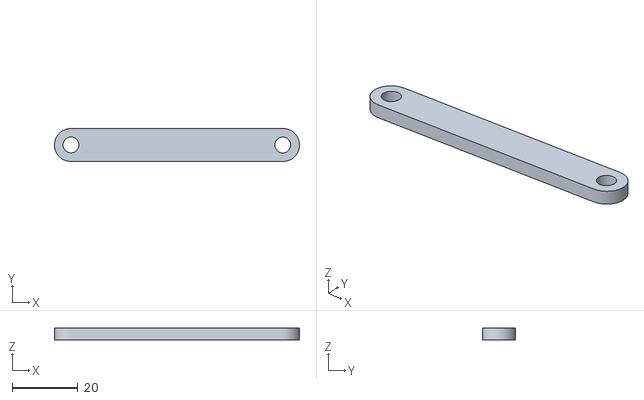
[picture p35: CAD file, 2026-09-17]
Finished Models/Main Box WRO_Configuration 1_bottom_linkage.stl
74.5 x 10.0 x 3.50

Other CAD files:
Finished Models/Main Box WRO_Configuration 1_design_steering_arm_right.stl

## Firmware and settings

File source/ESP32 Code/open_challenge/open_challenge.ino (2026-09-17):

/* ============================================================================
   WRO Future Engineers - OPEN CHALLENGE
   3 laps, then stop in the starting section.
   ----------------------------------------------------------------------------
   HOW IT WORKS
     Straight : PD wall-follow, centred between the two side walls
     Corner   : a side sensor reads long -> turn 90 deg USING THE GYRO
     Counting : 12 corners = 3 laps
     Finish   : after corner 12, keep following the wall for FINISH_MS, stop

   WHY THE GYRO RUNS THE TURN, NOT A TIMER
     A timed turn changes with battery voltage and floor grip, so it drifts
     over 12 corners. "Turn until the gyro says 90" is the same every time.
     After each corner the heading is SNAPPED to the nearest multiple of 90,
     which stops drift accumulating across the run.

   SET TUNING_MODE 1 FIRST. The motor stays off and sensors print.
   ============================================================================ */

#include <Wire.h>
#include <ESP32Servo.h>

#define TUNING_MODE 0        // 1 = print only, no driving. 0 = run.

/* --- pins --------------------------------------------------------------- */
const int PIN_PWMA   = 25;
const int PIN_AIN1   = 26;
const int PIN_AIN2   = 27;
const int PIN_SERVO  = 14;
const int PIN_TRIG_L = 32;
const int PIN_ECHO_L = 34;
const int PIN_TRIG_R = 33;
const int PIN_ECHO_R = 35;

// Start button: one leg to GPIO 23, the other to GND.
// INPUT_PULLUP means the pin reads HIGH when released, LOW when pressed,
// so no external resistor is needed.
const int PIN_START_BUTTON = 23;

/* --- tuning ------------------------------------------------------------- */
const int   SERVO_CENTER = 90;     // YOUR measured straight-ahead value

// Set to 1 if the robot steers the WRONG WAY.
// Depending on how the linkage is assembled and which way the servo horn
// was pressed on, increasing the servo angle may turn the wheels left on
// one build and right on another. This flips it in software instead of
// making you rebuild the linkage.
#define STEER_INVERT 1

// Set to 1 if yaw counts the WRONG WAY.
// The turn logic assumes yaw INCREASES when the robot turns right. Whether
// that is true depends on which way up the MPU6050 is mounted. If it is
// inverted, a right turn drives yaw away from its target and the robot
// turns forever.
//
// HOW TO CHECK: run with TUNING_MODE 1, rotate the robot clockwise by hand
// (viewed from above) and watch yaw in the telemetry. It must go UP.
#define GYRO_INVERT 1
// SERVO STALL WARNING. Two servos were destroyed at 60 degrees by
// stalling against the linkage's mechanical stop - the servo pushes at
// near stall current until the windings overheat, which takes several
// runs to kill it, so it looks fine until suddenly it is not.
//
// Currently set to 50. Verify with servo_sweep.ino that the linkage does
// not bind before this angle, and check the servo by hand after each run:
// warm is normal, too hot to hold comfortably means it is stalling.
const int   STEER_MAX    = 60;     // max deviation either side
const int   STEER_LOCK   = 60;     // deviation used during a corner

const int   SPEED_STRAIGHT = 110;
const int   SPEED_TURN     = 90;   // must be above your motor deadband

// Wall following
const float KP_WALL = 1.99f;
const float KD_WALL = 0.25f;

/* Extra push that grows with the SQUARE of the intrusion, so the response
   is gentle just inside the margin and firm when the wall is genuinely
   close. A purely proportional term cannot do both: set it soft enough
   not to twitch at 14 cm and it barely reacts at 3 cm; set it hard enough
   for 3 cm and it jerks the robot around at 14 cm.

   Divided by the margin so the term stays in degrees and the constant
   keeps its meaning if WALL_MARGIN_CM changes. */
const float KP_WALL_SQ = 1.33f;
const float TARGET_SIDE_CM = 50.0f;   // kept for the no-direction fallback

/* --- corridor margin ----------------------------------------------------
   The robot no longer tries to sit centred between the walls. It only
   steers when it comes within WALL_MARGIN_CM of a wall; anywhere in the
   middle it just holds its heading and drives straight.

   WHY: centring means the controller is always correcting, and every
   correction leaves the robot slightly angled. A robot at an angle gives
   bad ultrasonic readings, because the pulse strikes the wall off-square
   and reads long or not at all - which is what produced the false corners.
   Driving straight through the middle of the corridor removes most of
   that.

   The correction is proportional to how far INSIDE the margin the robot
   has come, so it is zero at exactly 15 cm and grows smoothly as the wall
   gets closer. That avoids the jerk of a hard on/off rule.
   ------------------------------------------------------------------------ */
const float WALL_MARGIN_CM = 25.0f;

// Gain for holding heading while in the clear middle of the corridor.
const float KP_HEADING_HOLD = 0.8f;



// Corner detection
const float CORNER_DIST_CM   = 120.0f;  // side reading above this = no wall
const int   CORNER_CONFIRM   = 2;       // ~80ms at 40ms per sensor


const float TURN_ANGLE       = 90.0f;

/* A turn may finish once yaw is within this many degrees of the target.

   At 30 this is a LARGE tolerance: a 90 degree turn can end after only 60
   degrees of sweep. That is deliberate - it stops the robot over-rotating
   - but it means each corner may leave the robot up to 30 degrees short.

   Two things keep that from compounding:
     - the both-walls check below usually ends the turn on real alignment
       rather than on this tolerance
     - the next corner targets an ABSOLUTE heading, so a short turn is
       corrected by the following one rather than accumulating           */
const float TURN_TOLERANCE_DEG = 20.0f;


/* Seeing a wall on BOTH sides again means the robot is back in a corridor,
   i.e. the turn is done - regardless of what the gyro thinks. This is an
   independent confirmation that does not accumulate drift. It is only
   trusted once the robot has already swept most of the turn, so that the
   corridor it came FROM cannot end the turn immediately. */
const float BOTH_WALLS_MIN_SWEEP = 75.0f;

// Consecutive confirmations before trusting the both-walls reading.
const int   CORRIDOR_CONFIRM  = 3;

/* Acceptable range for a commanded turn. Every corner on this track is 90
   degrees; the self-correcting heading target may legitimately ask for a
   bit more or less to straighten the robot up, but never double. Outside
   this band the rounding has gone wrong and we fall back to a plain 90. */
const float TURN_SWEEP_MIN   = 30.0f;
const float TURN_SWEEP_MAX   = 150.0f;
const unsigned long MIN_CORNER_GAP_MS = 1400;

// Gyro bias samples, 2ms each. Runs after the button, so it costs run time.
const int   GYRO_CAL_SAMPLES = 800;   // 1.6 s

// A 90 degree turn should take well under this. Exceeding it means
// something is wrong, so the robot stops instead of circling.
const unsigned long TURN_TIMEOUT_MS = 4000;



// Run length
const int   TOTAL_CORNERS = 12;         // 4 per lap x 3 laps
const unsigned long FINISH_MS = 500;   // TUNE: drive time after last corner

const float US_MAX_CM = 200.0f;
const unsigned long US_TIMEOUT_US = 12000;
const int MPU_ADDR = 0x68;

/* --- globals ------------------------------------------------------------ */
Servo steer;
float distL = US_MAX_CM, distR = US_MAX_CM;
float yaw = 0, gyroBias = 0, headingTarget = 0;
float prevError = 0;
int   cornerCount = 0;
int   longL = 0, longR = 0;
bool  noEchoL = false, noEchoR = false;
int   corridorCount = 0;
int   usTurn = 0;
int   turnDir = 0;                 // +1 right, -1 left. Set at first corner.
unsigned long lastLoop = 0, finishStart = 0, turnStartMs = 0;
unsigned long lastYawUs = 0;
float turnStartYaw = 0;
unsigned long lastCornerMs = 0;

enum State { WAIT, DRIVE, TURNING, FINISHING, DONE };
State state = WAIT;

/* --- MPU6050 ------------------------------------------------------------ */
void mpuInit() {
  Wire.begin(21, 22);
  Wire.setClock(400000);
  Wire.beginTransmission(MPU_ADDR); Wire.write(0x6B); Wire.write(0x00); Wire.endTransmission();
  Wire.beginTransmission(MPU_ADDR); Wire.write(0x1B); Wire.write(0x00); Wire.endTransmission();
  Wire.beginTransmission(MPU_ADDR); Wire.write(0x1A); Wire.write(0x03); Wire.endTransmission();
}
/* Reads the gyro's Z rate. Tracks consecutive failures so the rest of the
   program can fall back to timed turns instead of stalling forever. */
float gyroRaw() {
  Wire.beginTransmission(MPU_ADDR); Wire.write(0x47);
  Wire.endTransmission(false);
  Wire.requestFrom(MPU_ADDR, 2, true);
  if (Wire.available() < 2) return 0;
  int16_t v = (Wire.read() << 8) | Wire.read();
  return (float)v;
}
/* Measures the gyro's resting offset so it can be subtracted from every
   later reading.

   TIMING NOTE: this now runs AFTER the start button, so it is inside the
   scored run. At 2ms per sample, GYRO_CAL_SAMPLES directly sets how much
   dead time you spend before moving:

       400 samples  = 0.8 s   noisier bias, more heading drift per lap
       800 samples  = 1.6 s   good compromise (default)
      1500 samples  = 3.0 s   best bias, 3 s of your round gone

   The round is 3 minutes, so this is not critical, but it is free lap time
   if your gyro is well behaved. Check the printed bias across several runs:
   if it varies by more than about 5 counts, raise the sample count. */
void calibrateGyro() {
  Serial.println(F("gyro cal - HOLD STILL"));
  double s = 0;
  for (int i = 0; i < GYRO_CAL_SAMPLES; i++) { s += gyroRaw(); delay(2); }
  gyroBias = s / (double)GYRO_CAL_SAMPLES;
  Serial.print(F("bias ")); Serial.println(gyroBias, 1);
}
void updateYaw(float dt) {
  float r = (gyroRaw() - gyroBias) / 131.0f;
  if (fabs(r) < 0.6f) r = 0;
#if GYRO_INVERT
  r = -r;
#endif
  yaw += r * dt;
}

/* --- ultrasonic --------------------------------------------------------- */
/* Set true when the last ping TIMED OUT rather than returning a real
   echo. A timeout is ambiguous - it can mean "no wall" or "the pulse hit
   the wall at an angle and reflected away" - so the caller treats it with
   more suspicion than a genuine long reading. */
bool lastPingTimedOut = false;

float ping(int trig, int echo) {
  digitalWrite(trig, LOW);  delayMicroseconds(3);
  digitalWrite(trig, HIGH); delayMicroseconds(10);
  digitalWrite(trig, LOW);
  unsigned long us = pulseIn(echo, HIGH, US_TIMEOUT_US);

  /* pulseIn returns 0 when it TIMES OUT - no echo came back within 12ms,
     which is about 2 metres. That means nothing is in range, i.e. FAR.
     Being too close does not cause a timeout; it produces a very short
     pulse and reads as a small number.

     So 0 must map to US_MAX_CM, not to 0. Returning 0 would tell the wall
     follower a wall is touching the robot, and would stop the
     distL >= CORNER_DIST_CM test from ever being true, which disables
     side-based corner detection entirely. */
  if (us == 0) { lastPingTimedOut = true; return US_MAX_CM; }
  lastPingTimedOut = false;
  float cm = us / 58.0f;
  return (cm > US_MAX_CM) ? US_MAX_CM : cm;
}

/* One sensor per loop, alternating. Firing both at once means each hears
   the other's echo. Each sensor refreshes every 2 loops, about 40ms. */
void updateUltrasonics() {
  if (usTurn == 0) { distL = ping(PIN_TRIG_L, PIN_ECHO_L); noEchoL = lastPingTimedOut; }
  else             { distR = ping(PIN_TRIG_R, PIN_ECHO_R); noEchoR = lastPingTimedOut; }
  usTurn ^= 1;
}

/* --- actuators ---------------------------------------------------------- */
void motor(int s) {
#if TUNING_MODE
  s = 0;
#endif
  s = constrain(s, -255, 255);
  digitalWrite(PIN_AIN1, s > 0 ? HIGH : LOW);
  digitalWrite(PIN_AIN2, s < 0 ? HIGH : LOW);
#if ESP_ARDUINO_VERSION_MAJOR >= 3
  ledcWrite(PIN_PWMA, abs(s));
#else
  ledcWrite(0, abs(s));
#endif
}
void steerTo(float dev) {
#if STEER_INVERT
  dev = -dev;
#endif
  dev = constrain(dev, -STEER_MAX, STEER_MAX);
  steer.write(SERVO_CENTER + (int)dev);
}
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
void loop() {
  /* GYRO FIRST, EVERY ITERATION.

     pulseIn() blocks for up to 12ms when a sensor gets no echo, so the old
     fixed 20ms loop could stretch to 40ms or more. The gyro was sampled
     once per loop, which meant integrating at an irregular 25-50Hz and
     applying each rate reading across the whole gap. That is why turns came
     out inconsistent - sometimes over, sometimes under.

     Now yaw integrates as fast as the loop can run, using real elapsed
     micros, and the slow sensor work is throttled separately below.     */
  unsigned long nowUs = micros();
  float dt = (nowUs - lastYawUs) / 1000000.0f;
  lastYawUs = nowUs;
  if (dt > 0.2f) dt = 0.2f;            // ignore absurd gaps after a stall
  updateYaw(dt);

  unsigned long now = millis();
  if (now - lastLoop < 20) return;
  lastLoop = now;

  /* Ultrasonics are skipped during the FIRST part of a turn: they are not
     needed there, and pulseIn blocking would thin out the gyro sampling
     exactly when the turn accuracy depends on it.

     Once the robot has swept past BOTH_WALLS_MIN_SWEEP they come back on, so
     the early-exit check below has data to work with. */
  bool lateInTurn = (state == TURNING) &&
                    (fabs(yaw - turnStartYaw) >= BOTH_WALLS_MIN_SWEEP);
  if (state != TURNING || lateInTurn) updateUltrasonics();

  // Debounced "wall has gone" detection
  if (distL >= CORNER_DIST_CM) longL++; else longL = 0;
  if (distR >= CORNER_DIST_CM) longR++; else longR = 0;


  switch (state) {

    case WAIT:                  // safe idle - not used in normal flow,
      motor(0);                 // the button wait now happens in setup()
      steerTo(0);
      break;

    case DRIVE: {
      steerTo(wallSteer());
      motor(SPEED_STRAIGHT);

      /* CORNER DETECTION: a side wall disappearing.

         The exclusivity check - one side long while the other is NOT -
         stops an open area on both sides from triggering a random turn. */
      bool cornerL = (longL >= CORNER_CONFIRM) && (longR < CORNER_CONFIRM);
      bool cornerR = (longR >= CORNER_CONFIRM) && (longL < CORNER_CONFIRM);

      // Corners are physically far apart, so a detection too soon after
      // the last one is spurious. This guard does not depend on any sensor
      // being accurate, unlike a heading-based check.
      bool spacedOut = (millis() - lastCornerMs) > MIN_CORNER_GAP_MS;

      if ((cornerL || cornerR) && spacedOut) {
        // Lap direction is decided by the FIRST corner, because the start
        // direction is randomised. Do not assume clockwise.
        if (turnDir == 0) {
          turnDir = cornerL ? -1 : +1;
          Serial.print(F("direction: "));
          Serial.println(turnDir > 0 ? F("clockwise") : F("anticlockwise"));
        }
        // ABSOLUTE heading target, not a relative sweep.
        //
        // The track is a rectangle, so every legal heading is a multiple
        // of 90 degrees. round(yaw/90)*90 gives the heading we SHOULD have
        // been on; adding 90 in the turn direction gives the heading we
        // should end up on.
        //
        // This self-corrects. Entering a corner 30 degrees crooked means
        // the robot turns 60 or 120 degrees as needed to come out straight,
        // instead of turning a blind 90 and staying 30 degrees off.
        /* Absolute heading target, with a sanity clamp.

           round(yaw/90) self-corrects small heading errors, which is what
           we want. But it has a cliff: once the robot is more than 45
           degrees off, round() snaps to the WRONG multiple of 90 and the
           commanded turn jumps by a full 90 degrees. Measured: at yaw -134
           the sweep is 46 degrees; at -136 it becomes 136 degrees.

           So compute the target, then check how far it actually asks the
           robot to turn. A corner on this track is 90 degrees. Anything
           outside a sensible band means the rounding went over the cliff,
           and we fall back to a plain 90 from the current heading.       */
        headingTarget = round(yaw / 90.0f) * 90.0f + turnDir * TURN_ANGLE;

        float sweep = fabs(headingTarget - yaw);
        if (sweep < TURN_SWEEP_MIN || sweep > TURN_SWEEP_MAX) {
          Serial.print(F("  sweep ")); Serial.print(sweep, 0);
          Serial.println(F(" deg out of range - using plain 90"));
          headingTarget = yaw + turnDir * TURN_ANGLE;
        }
        turnStartMs = millis();
        turnStartYaw = yaw;
        corridorCount = 0;
        lastCornerMs = millis();
        state = TURNING;
        Serial.print(F("corner ")); Serial.println(cornerCount + 1);
      }
      break;
    }

    case TURNING: {
      steerTo(turnDir * STEER_LOCK);
      motor(SPEED_TURN);

      float swept = fabs(yaw - turnStartYaw);

      /* Two independent ways to finish a turn.

         1. GYRO - yaw within TURN_TOLERANCE_DEG of the target, or past it.
            Tolerance matters because tyre scrub or a brush against a wall
            can eat the last few degrees; without it the turn hangs until
            the timeout and the corner never gets counted.

         2. BOTH WALLS - a wall visible on both sides means the robot is
            back in a corridor and pointing down it. That is physical
            evidence of alignment, so it ends the turn whatever the gyro
            says. Valuable precisely because it does NOT drift: if the gyro
            is slowly accumulating error, the walls still tell the truth.

            Only trusted after BOTH_WALLS_MIN_SWEEP degrees, otherwise the
            corridor the robot came FROM would end the turn immediately.
            Confirmed over several readings, since ultrasonics mis-read.

            When the walls end the turn, yaw is set to the target - the
            walls say we ARE aligned, so this is an evidence-based
            correction rather than a blind snap.                          */
      bool byGyro = fabs(yaw - headingTarget) <= TURN_TOLERANCE_DEG;
      if (turnDir > 0 && yaw >= headingTarget) byGyro = true;
      if (turnDir < 0 && yaw <= headingTarget) byGyro = true;

      bool byWalls = false;
      if (!byGyro && swept >= BOTH_WALLS_MIN_SWEEP) {
        if (distL < CORNER_DIST_CM && distR < CORNER_DIST_CM) corridorCount++;
        else                                                  corridorCount = 0;

        if (corridorCount >= CORRIDOR_CONFIRM) {
          Serial.print(F("  corridor found at yaw ")); Serial.print(yaw, 0);
          Serial.print(F(" (target ")); Serial.print(headingTarget, 0);
          Serial.print(F("), swept ")); Serial.print(swept, 0);
          Serial.println(F(" deg - ending turn"));
          yaw = headingTarget;
          byWalls = true;
        }
      }

      bool reached = byGyro || byWalls;

      // SAFETY: a turn should never take more than a few seconds. If it
      // does, the gyro sign is likely wrong - see GYRO_INVERT.
      if (!reached && millis() - turnStartMs > TURN_TIMEOUT_MS) {
        motor(0);
        steerTo(0);
        Serial.println(F("!! TURN TIMEOUT - check GYRO_INVERT"));
        Serial.print(F("   yaw=")); Serial.print(yaw, 1);
        Serial.print(F(" target=")); Serial.println(headingTarget, 1);
        state = DONE;
        break;
      }

      if (reached) {
        // NOTE: we deliberately do NOT snap yaw to a multiple of 90 here.
        // Snapping made the numbers look clean while leaving the robot
        // physically crooked, and the error compounded corner after corner.
        // Because the next turn targets an absolute heading, any residual
        // error is corrected by the turn itself.
        headingTarget = round(yaw / 90.0f) * 90.0f;
        lastCornerMs = millis();      // gap measured from turn EXIT
        prevError = 0;
        longL = longR = 0;
        corridorCount = 0;

        /* INVALIDATE STALE DISTANCES.

           Ultrasonics are skipped during most of a turn, so these values
           can still describe the corner the robot just came out of. Acting
           on them in DRIVE made the robot clamp its steering as if a wall
           were still close ahead, so it could not correct its line and
           drove into the wall.

           Setting them to maximum means "unknown, assume clear" until a
           real reading arrives, which takes about 60ms. */
        distL = distR = US_MAX_CM;
        cornerCount++;

        if (cornerCount >= TOTAL_CORNERS) {
          finishStart = millis();
          state = FINISHING;
          Serial.println(F("3 laps done - heading to start section"));
        } else {
          state = DRIVE;
        }
      }
      break;
    }
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

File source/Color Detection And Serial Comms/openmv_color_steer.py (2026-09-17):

# OpenMV Cam H7+ -> ESP32 : dominant colour detection
# ---------------------------------------------------
# Finds which pillar colour occupies the most of the frame and tells the
# ESP32 about it. The ESP32 then steers.
#
# Protocol, newline terminated:
#     R,<cx>,<total_px>     red is dominant    -> ESP32 steers RIGHT
#     G,<cx>,<total_px>     green is dominant  -> ESP32 steers LEFT
#     M,<cx>,<total_px>     magenta (parking marker) - no steering
#     N,0,0                 nothing above threshold
#     F,<fps>               frame rate, about once a second
#
# WHY TWO NUMBERS
#   total_px decides WHICH colour wins (how much of that colour is on
#   screen). cx is the centre of the BIGGEST single blob of that colour,
#   which is the nearest pillar and the one worth steering around.
#   Using total_px for position would average two pillars into a point
#   between them, and the robot would drive at the gap.
#
# WIRING: OpenMV P4 (TX) -> ESP32 GPIO16 (RX). Common ground REQUIRED.

import sensor
import time
from pyb import UART, LED

led_red = LED(1)
led_green = LED(2)
led_blue = LED(3)
for _l in (led_red, led_green, led_blue):
    _l.off()

uart = UART(3, 115200, timeout_char=1000)

# ---------------- camera ----------------
MANUAL_GAIN_DB = 12.0     # None = use whatever auto settles on
SATURATION = 3            # stretches the A/B axes the thresholds key on

sensor.reset()
sensor.set_pixformat(sensor.RGB565)
sensor.set_framesize(sensor.QVGA)          # 320 x 240

sensor.set_auto_gain(True)
sensor.set_auto_whitebal(True)
sensor.set_auto_exposure(True)
sensor.skip_frames(time=2500)

settled_gain = sensor.get_gain_db()
settled_exp = sensor.get_exposure_us()
settled_rgb = sensor.get_rgb_gain_db()
use_gain = settled_gain if MANUAL_GAIN_DB is None else MANUAL_GAIN_DB

sensor.set_auto_gain(False, gain_db=use_gain)
sensor.set_auto_exposure(False, exposure_us=int(settled_exp))
sensor.set_auto_whitebal(False, rgb_gain_db=settled_rgb)

for _name, _fn, _v in (("saturation", sensor.set_saturation, SATURATION),
                       ("contrast", sensor.set_contrast, 1),
                       ("brightness", sensor.set_brightness, 1)):
    try:
        _fn(_v)
    except Exception:
        print("%s not supported" % _name)

sensor.skip_frames(time=500)
print("gain %.1fdB exp %dus" % (sensor.get_gain_db(), sensor.get_exposure_us()))

# ---------------- thresholds ----------------
# (L min, L max, A min, A max, B min, B max)
# Widened for a dim frame. Re-tune with Tools > Machine Vision >
# Threshold Editor once your lighting is sorted.
RED_THRESHOLD     = (12,  75,   30, 127,    8,  90)
GREEN_THRESHOLD   = (20, 100, -100, -20,   15, 110)
MAGENTA_THRESHOLD = (12,  85,   40, 127, -105, -15)

MIN_TOTAL_PX = 400        # ignore a colour below this total area
SEND_INTERVAL_MS = 50     # ~20 Hz
FPS_INTERVAL_MS = 1000

# Region of interest (x, y, w, h). Crops off the far wall.
ROI = (0, 60, 320, 180)

clock = time.clock()
last_send = time.ticks_ms()
last_fps = time.ticks_ms()
heartbeat = 0


def val(attr):
    """Blob accessors are properties on newer firmware, methods on older."""
    return attr() if callable(attr) else attr


def measure(img, threshold):
    """Return (total_pixels, cx_of_largest_blob).

    total_pixels answers 'how much of this colour is on screen'.
    cx comes from the single biggest blob - the nearest pillar."""
    kwargs = dict(pixels_threshold=100, area_threshold=100,
                  merge=True, margin=10)
    if ROI:
        kwargs['roi'] = ROI
    blobs = img.find_blobs([threshold], **kwargs)

    total = 0
    best_px = 0
    best_cx = 160
    for b in blobs:
        px = val(b.pixels)
        total += px
        if px > best_px:
            best_px = px
            best_cx = int(val(b.cx))
    return total, best_cx


try:
  while True:
    clock.tick()
    img = sensor.snapshot()

    r_total, r_cx = measure(img, RED_THRESHOLD)
    g_total, g_cx = measure(img, GREEN_THRESHOLD)
    m_total, m_cx = measure(img, MAGENTA_THRESHOLD)

    # Dominant colour = the one covering the most of the frame
    colour = 'N'
    cx = 0
    total = 0
    if r_total >= g_total and r_total >= m_total and r_total >= MIN_TOTAL_PX:
        colour, cx, total = 'R', r_cx, r_total
    elif g_total >= m_total and g_total >= MIN_TOTAL_PX:
        colour, cx, total = 'G', g_cx, g_total
    elif m_total >= MIN_TOTAL_PX:
        colour, cx, total = 'M', m_cx, m_total

    # ---- overlay, cosmetic only, must never crash the loop ----
    try:
        if colour != 'N':
            c = {'R': (255, 0, 0),
                 'G': (0, 255, 0),
                 'M': (255, 0, 255)}[colour]
            img.draw_cross(cx, 120, color=c, size=20)
            img.draw_string(4, 4, "%s %d" % (colour, total), color=c)
        if ROI:
            img.draw_rectangle(ROI, color=(40, 40, 40))
    except Exception:
        pass

    # ---- status LEDs, readable with no laptop attached ----
    led_red.off()
    led_green.off()
    if colour == 'R':
        led_red.on()
    elif colour == 'G':
        led_green.on()
    elif colour == 'M':
        led_red.on()
        led_blue.on()

    heartbeat = (heartbeat + 1) % 15
    if heartbeat == 0 and colour != 'M':
        led_blue.toggle()

    # ---- transmit ----
    now = time.ticks_ms()
    if time.ticks_diff(now, last_send) >= SEND_INTERVAL_MS:
        last_send = now
        if colour == 'N':
            uart.write("N,0,0\n")
        else:
            uart.write("%s,%d,%d\n" % (colour, cx, total))

    if time.ticks_diff(now, last_fps) >= FPS_INTERVAL_MS:
        last_fps = now
        uart.write("F,%.1f\n" % clock.fps())

    # Uncomment to debug in the IDE. Costs fps - leave off on the robot.
    # print(colour, total, cx, clock.fps())

except Exception as e:
    try:
        uart.write("N,0,0\n")
    except Exception:
        pass
    led_green.off()
    led_blue.off()
    while True:
        led_red.toggle()
        time.sleep_ms(120)

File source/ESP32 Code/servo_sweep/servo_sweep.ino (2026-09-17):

/* Slow servo sweep test - ESP32 + MG90S
   -------------------------------------
   Sweeps slowly left and right, printing the angle as it goes.
   Watch the serial monitor AND listen to the servo.

   WHAT YOU ARE LOOKING FOR:
     The angle where the servo starts to buzz or strain, or where the
     wheels stop moving but the servo keeps pushing. That is a
     mechanical limit. A servo held against a limit draws close to an
     amp continuously, which is what collapses your power rail.

     Note the angle it happens at, then set your STEER_LOCK a few
     degrees inside it.

   RUN THIS WITH THE MOTOR UNPLUGGED, as you have been doing.
   Start with a NARROW range and widen it once you know it is safe. */

#include <ESP32Servo.h>

const int PIN_SERVO = 14;

const int CENTER    = 90;    // your straight-ahead value
const int SWEEP     = 55;    // degrees either side. START SMALL. Raise to 20, 25...
const int STEP_MS   = 1;    // ms per degree. Higher = slower sweep.

Servo steer;

void setup() {
  Serial.begin(115200);
  delay(300);

  ESP32PWM::allocateTimer(1);
  ESP32PWM::allocateTimer(2);
  ESP32PWM::allocateTimer(3);
  steer.setPeriodHertz(50);
  steer.attach(PIN_SERVO, 500, 2400);

  steer.write(CENTER);
  Serial.println(F("centering..."));
  delay(1000);
  Serial.print(F("sweeping "));
  Serial.print(CENTER - SWEEP);
  Serial.print(F(" to "));
  Serial.println(CENTER + SWEEP);
}

void loop() {
  steer.write(CENTER + SWEEP);
  delay(1500);

  steer.write(CENTER - SWEEP);
  delay(1500);
}

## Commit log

2026-07-14 Implemented the ESP32 code for serial omunication.
2026-07-14 Add ESP32 color detection and UART communication
2026-07-14 Uploaded Proper Files and correct directoris
    [ESP32code.ino, OpenMV Cam.py]
2026-09-17 Updated entire GitHub
    Finished the whole robot and added all the items we have used to the GitHub alongside photos of the robot.
    [Main Box WRO_Configuration 1_Battery Holder.stl, Main Box WRO_Configuration 1_bottom_linkage.stl, Main Box WRO_Configuration 1_design_steering_arm_left.stl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]
